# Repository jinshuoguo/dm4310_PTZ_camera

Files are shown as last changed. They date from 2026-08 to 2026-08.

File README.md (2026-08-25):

# DM4310 云台相机

<p align="center">
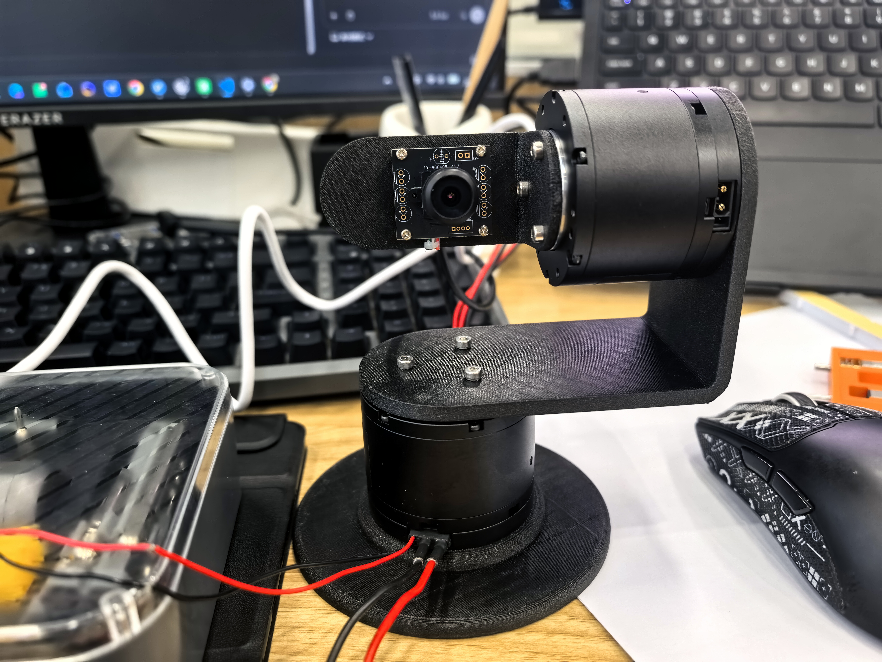
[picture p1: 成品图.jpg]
DM4310 双轴云台相机成品
  
</p>

<p align="center">
  基于双 DM-J4310 电机、USB2FDCAN 与机器视觉构建的双轴智能云台相机
</p>

<p align="center">
  
  
  
  
  
</p>

## 项目简介

这是一个从电机通信、运动控制、机械结构到视觉交互完整落地的双轴云台项目。
系统通过 USB2FDCAN 控制两台 DM-J4310 电机，支持键盘、Xbox 手柄和手机
局域网遥控，并使用相机完成实时画面回传、人脸跟随与手部跟随。

项目不只实现了“让电机转起来”，还围绕真实硬件补充了 S 曲线启停、软限位、
反馈超时保护、超速保护、静摩擦补偿、平滑归零、动作录制复现和断联自动失能，
形成了一套可交互、可演示、可继续扩展的云台控制系统。

## 核心功能

- **双轴实时控制**：经典 CAN 1 Mbps，同一总线独立控制水平轴与俯仰轴。
- **多种交互方式**：键盘、Xbox 左摇杆、手机横屏虚拟摇杆均可控制速度和方向。
- **机器视觉跟随**：基于 MediaPipe 与 OpenCV 实现人脸、手部目标检测和云台闭环跟随。
- **局域网控制台**：手机端同时提供摇杆、实时 MJPEG 画面、状态遥测与功能按钮。
- **位置与动作记忆**：保存/返回双电机位置，录制位置—时间轨迹并自适应复现。
- **拖动示教**：手动拖动一台电机，另一台电机按相对角度同步跟随。
- **高精度归零**：限速、限加速度接近零点，使用捕获区与积分前馈补偿静摩擦。
- **安全保护**：急停、软限位、超速、反馈错误、相机丢失、手柄断开和网络断联保护。

## 动态演示

GIF 会在 GitHub 页面中自动循环播放。每张动图均匀采样了对应演示的完整过程；
点击“高清原片”可以查看或下载 MP4 版本。

<table>
  <tr>
    <td width="50%" align="center">
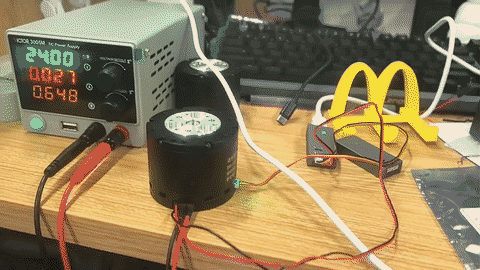
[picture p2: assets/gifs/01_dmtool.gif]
达妙官方工具驱动电机
      <br>
      <b>01 · 官方工具打通硬件链路</b><br>
      <sub>核对电机参数、CAN ID 与通信状态</sub><br>
      <a href="./达妙官方调试软件驱动电机.mp4">高清原片</a>
    </td>
    <td width="50%" align="center">
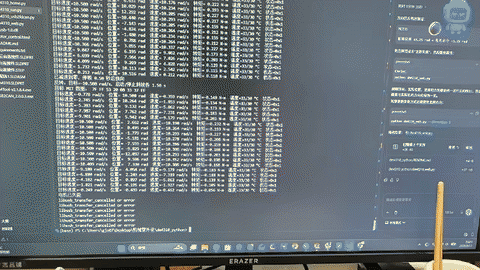
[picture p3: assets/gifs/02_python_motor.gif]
Python 驱动电机
      <br>
      <b>02 · Python 驱动单电机</b><br>
      <sub>USB2FDCAN 使能、控制与反馈解析</sub><br>
      <a href="./python驱动电机.mp4">高清原片</a>
    </td>
  </tr>
  <tr>
    <td width="50%" align="center">
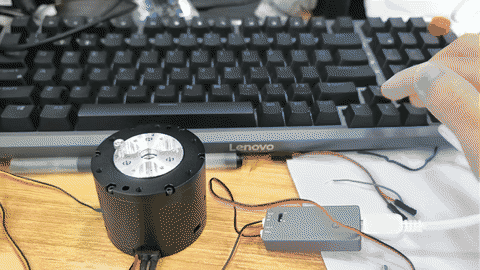
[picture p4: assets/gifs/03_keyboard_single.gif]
键盘控制单电机
      <br>
      <b>03 · 键盘控制单电机</b><br>
      <sub>速度控制与 0.1 秒快速平滑启停</sub><br>
      <a href="./基于python键盘控制电机.mp4">高清原片</a>
    </td>
    <td width="50%" align="center">
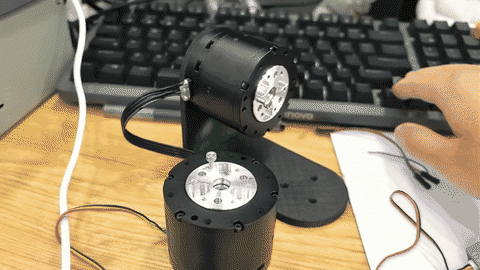
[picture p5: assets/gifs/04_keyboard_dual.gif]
键盘控制双电机
      <br>
      <b>04 · 键盘控制双电机</b><br>
      <sub>两组方向键独立控制水平与俯仰轴</sub><br>
      <a href="./基于python键盘控制双电机.mp4">高清原片</a>
    </td>
  </tr>
  <tr>
    <td width="50%" align="center">
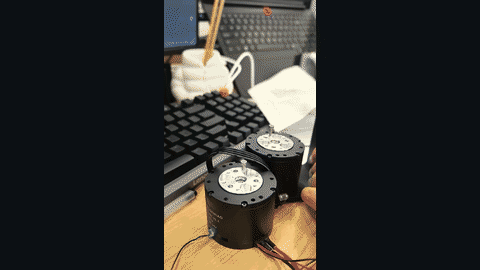
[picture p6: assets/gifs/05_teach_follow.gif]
双电机拖动示教
      <br>
      <b>05 · 双电机拖动示教</b><br>
      <sub>手动拖动一台电机，另一台同步跟随</sub><br>
      <a href="./一个电机控制另一个电机.mp4">高清原片</a>
    </td>
    <td width="50%" align="center">
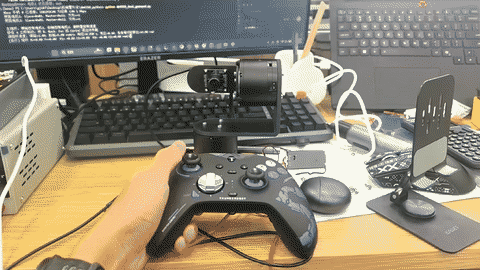
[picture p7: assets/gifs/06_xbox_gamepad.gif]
Xbox 手柄控制云台
      <br>
      <b>06 · Xbox 手柄遥控</b><br>
      <sub>摇杆方向和幅度映射双轴目标速度</sub><br>
      <a href="./xbox手柄控制云台.mp4">高清原片</a>
    </td>
  </tr>
  <tr>
    <td width="50%" align="center">
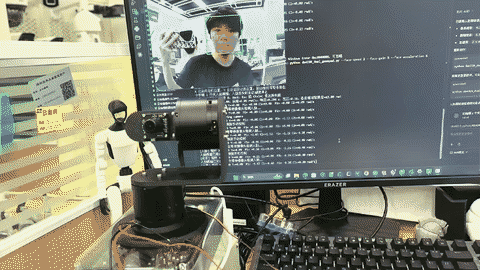
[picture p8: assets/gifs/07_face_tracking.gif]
人脸自动跟随
      <br>
      <b>07 · 人脸自动跟随</b><br>
      <sub>根据人脸中心偏差驱动双轴闭环</sub><br>
      <a href="./人脸跟随.mp4">高清原片</a>
    </td>
    <td width="50%" align="center">
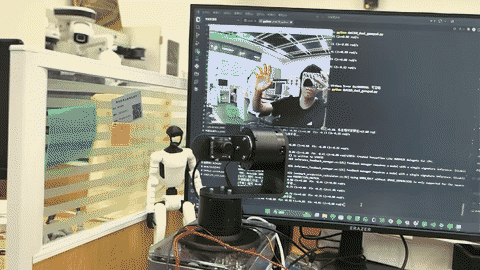
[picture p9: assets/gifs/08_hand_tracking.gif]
手部自动跟随
      <br>
      <b>08 · 手部自动跟随</b><br>
      <sub>使用掌心关键点控制云台视线</sub><br>
      <a href="./手部自动跟踪.mp4">高清原片</a>
    </td>
  </tr>
  <tr>
    <td colspan="2" align="center">
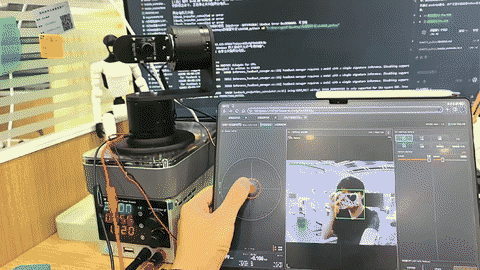
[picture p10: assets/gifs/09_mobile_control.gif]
手机局域网控制云台
      <br>
      <b>09 · 手机局域网控制台</b><br>
      <sub>横屏摇杆、状态遥测、自动功能与实时画面回传</sub><br>
      <a href="./局域网设备控制云台.mp4">高清原片</a>
    </td>
  </tr>
</table>

## 系统架构

```mermaid
flowchart LR
    KB[键盘] --> CTRL
    PAD[Xbox 手柄] --> CTRL
    PHONE[手机横屏控制台] <-->|HTTP / MJPEG| CTRL[Python 控制层]
    CAM[USB 相机] --> VISION[MediaPipe / OpenCV]
    VISION --> CTRL

    CTRL --> PLAN[轨迹规划与模式管理]
    PLAN --> SAFE[软限位 / 超速 / 超时 / 急停]
    SAFE --> SDK[dmcan SDK]
    SDK --> ADAPTER[USB2FDCAN]
    ADAPTER -->|Classic CAN 1 Mbps| M1[电机 1 · Pan\n0x01 / 0x11]
    ADAPTER -->|Classic CAN 1 Mbps| M2[电机 2 · Tilt\n0x02 / 0x12]
```

## 技术实现

### 电机与总线

- 两台 DM-J4310 共用 CAN_H/CAN_L，总线两端配置 120 Ω 终端电阻。
- 电机 1 使用 Slave/Master ID `0x01/0x11`，电机 2 使用 `0x02/0x12`。
- 通过 `dmcan-sdk` 调用 USB2FDCAN，使用经典 CAN 1 Mbps 和 MIT 控制报文。
- 解码位置、速度、转矩、状态与错误码，任一轴异常时联动失能两台电机。

### 运动控制

- 使用限速度、限加速度的速度/位置轨迹，避免阶跃指令冲击机械结构。
- 归零过程根据剩余制动距离调整速度，在零点附近切换到位置捕获阶段。
- 对位置反馈的 ±12.5 rad 回绕进行连续化处理，防止跨量程误判和突然高速旋转。
- 使用渐增位置刚度与限幅积分前馈克服减速器静摩擦，将归零目标误差设为
  `0.005 rad`。
- 动作复现采用自适应时间轴：跟随误差增大时减慢或暂停轨迹，待电机追上后继续。

### 视觉与交互

- 人脸跟随使用 MediaPipe 人脸检测结果，并以关键点中心作为稳定跟踪目标。
- 手部跟随使用 21 个关键点中的掌根和指根区域估计掌心，降低手指动作带来的抖动。
- 视觉控制加入中心死区、目标丢失超时、速度上限和加速度限制。
- 手机端为横屏布局：左侧虚拟摇杆、中间实时画面、右侧自动功能与安全按钮。
- 控制页面使用随机访问令牌；摇杆数据停止 `0.25 s` 后减速，断联超过 `1.2 s`
  自动失能。

## 开发经历

### 1. 打通硬件链路

首先使用达妙官方调试工具确认电机能够校准和转动，并读取固件、电压、CAN ID
与波特率。调试中发现设备虽然在 Windows 中显示为 COM 口，但实际控制接口是
USB2FDCAN SDK，而不是普通串口透传；随后改用 `dmcan-sdk` 完成经典 CAN 报文收发，
解决了“串口有输出但 CAN 帧无法发送”的问题。

### 2. 从单电机测试到安全运动控制

完成使能、MIT 指令打包、反馈解析和异常失能后，先以低速验证单电机正反转。
随后加入 S 曲线缓启动/缓停止、方向映射和相对软限位，使按键控制既敏捷又不会
对结构产生明显冲击。

### 3. 改进高精度归零算法

早期位置插值归零在编码器回绕附近出现过位置跳变和瞬时高速，接近零位时又受到
减速器静摩擦影响，存在稳态误差。为此重新设计两阶段归零：远端采用制动距离限速，
近端先降速再渐增位置刚度，同时加入带限幅、带抗饱和的积分前馈。最终将归零判定
改为“位置与速度同时满足并持续稳定”，目标误差收紧到 `0.005 rad`。

### 4. 扩展双轴、示教与手柄控制

第二台电机接入同一 CAN 总线后，为两轴建立独立 ID、状态与软限位，并实现键盘
并行控制。随后加入拖动示教功能：电机 2 提供低力矩摩擦补偿以便手动拖动，电机 1
跟随其相对角度。Xbox 控制则加入圆形死区、响应曲线、主轴锁定与平滑加减速，减少
上下推动时误触左右轴的问题。

### 5. 加入视觉闭环

在人脸检测方案中，从受光照和侧脸影响较大的传统分类器切换到 MediaPipe；手部跟随
则选取较稳定的掌心区域而不是单个指尖。视觉偏差被转换为两轴目标速度，同时设置
中心死区、目标丢失停车和人工摇杆接管，让自动跟随不会与手动控制争抢控制权。

### 6. 实现动作录制与鲁棒复现

系统以固定周期记录两轴位置和相对时间。直接按原时间播放时，实际电机可能因速度、
负载不同而产生过大跟随误差，因此加入“先返回录制起点 + 自适应时间轴”策略：误差
增大时自动放慢，超过暂停阈值时等待电机追上，仅在触发硬保护阈值时失能。

### 7. 完成局域网手机控制台

最后将手柄端功能迁移到手机横屏网页，整合虚拟摇杆、实时遥测、人脸/手部跟随、
位置记忆、动作录制复现和 MJPEG 画面回传。服务端加入访问令牌、控制心跳和断联
看门狗，使手机可以作为无需安装 App 的便携控制器。

### 8. 机械结构迭代

根据两台电机和相机的实际尺寸设计底盘、云台连接件与相机固定架，并保留 SolidWorks
源文件及 STEP 通用格式，完成从控制算法到实体装配的闭环验证。

## 安全机制

真实电机控制具有风险，项目默认采用以下保护：

- 启动位置附近的相对软限位，防止机构持续绕线或碰撞。
- 超速、错误码、反馈中断、手柄断开和网络断联触发停车或失能。
- 自动跟随、回位和动作复现过程中，人工摇杆输入可立即接管。
- 手机端提供急停按钮，脚本在 `Ctrl+C`、异常或正常退出时发送失能指令。
- 运行任一控制脚本前，应关闭 DMTool 等其他占用 USB2FDCAN 的程序。

> 首次运行请悬空或固定机构、降低速度，并确保随时可以切断 24 V 电源。

## 快速开始

### 1. 环境

- Windows 10/11
- Python 3.13（项目验证环境为 Conda base）
- 达妙 USB2FDCAN 与两台 DM-J4310
- 24 V 直流电源
- USB 相机；Xbox 手柄为可选设备

### 2. 安装依赖

```powershell
Set-Location .\dm4310_python
python -m pip install -r requirements.txt
```

运行前关闭 DMTool 和 USB2CAN 图形工具，避免设备被重复占用。

### 3. 选择控制方式

```powershell
# 单电机低速验证
python dm4310_usb2fdcan.py

# 双轴键盘控制
python dm4310_dual_keyboard.py

# Xbox 手柄、视觉跟随、位置记忆和动作录制
python dm4310_dual_gamepad.py

# 手机局域网控制与视频回传
python dm4310_mobile.py
```

更完整的接线、参数和各脚本使用方法见
[Python 控制说明](./dm4310_python/README.md)。

## 项目结构

```text
云台相机/
├─ README.md                         # GitHub 项目主页
├─ 成品图.jpg                        # 实物展示
├─ *.mp4                            # 功能演示视频
├─ assets/gifs/                     # README 轻量循环动图
├─ tools/make_readme_gifs.py        # MP4 批量生成 GIF 预览工具
├─ *.SLDPRT / *.SLDASM / *.STEP     # 机械设计源文件与通用模型
└─ dm4310_python/
   ├─ dm4310_usb2fdcan.py           # 单电机通信与低速测试
   ├─ dm4310_home.py                # 高精度平滑归零
   ├─ dm4310_keyboard.py            # 单电机键盘控制
   ├─ dm4310_dual_keyboard.py       # 双电机键盘控制
   ├─ dm4310_teach_follow.py        # 拖动示教跟随
   ├─ dm4310_dual_gamepad.py        # 手柄、视觉、录制复现主程序
   ├─ dm4310_face_tracker.py        # 人脸与手部检测封装
   ├─ dm4310_mobile.py              # 局域网手机控制服务
   ├─ mobile_controller.html        # 手机横屏控制界面
   ├─ dm4310_web.py                 # 单轴网页位置控制服务
   └─ requirements.txt              # Python 依赖
```

## 后续计划

- 接入小智 AI 语音，通过 MCP 将自然语言安全映射为跟随、回位、录制和急停等离散工具。
- 增加双轴机械零位开关与上电自动标定。
- 将相机跟踪升级为带目标选择和丢失重识别的多目标跟踪。
- 保存动作轨迹到文件，并提供轨迹编辑、命名和管理界面。

## 说明

本仓库面向个人学习、机器人控制实验和作品集展示。项目直接驱动真实电机，复现时请
根据自己的机械结构重新确认 CAN ID、安装方向、软限位、电源能力和急停方案。

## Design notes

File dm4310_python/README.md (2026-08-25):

# DM4310 云台相机

基于双轴 DM-J4310 电机、USB2FDCAN、相机视觉、手柄与局域网手机端的云台相机控制项目。

当前设备在调试工具中显示为 `COM10-USB2FDCAN`，应使用 USB2FDCAN SDK，
而不是旧版 COM 串口封装。

## 安装

依赖和官方 Windows DLL 已放入当前目录。请使用 Conda base 的 Python 3.13，
不要使用指向 Python 3.15 alpha 的 `py` 启动器。

运行前必须完全关闭 DM_Tools 和 USB2CAN 图形工具，确保 COM10 没有被占用。

## USB2FDCAN 首次低速测试

1. 完全关闭 DMTool 和 USB2CAN 图形程序。
2. 固定或悬空电机。
3. 在 `(base)` 终端运行：

```powershell
python dm4310_usb2fdcan.py
```

默认参数：

- Slave ID：0x01
- Master ID：0x11
- CAN：经典 CAN 1 Mbps
- 速度：0.5 rad/s
- 时间：5 秒
- 缓启动、缓停止时间：各 1.5 秒（S 曲线）
- MIT 参数：KP=0、KD=1、Torque=0

程序结束、报错或按 `Ctrl+C` 时都会发送失能命令。

根据当前调试工具截图，实际 Slave ID 是 `0x01`，Master ID 是 `0x11`；
新脚本也以这两个值为默认值。

修改速度和运行时间：

```powershell
python dm4310_usb2fdcan.py --speed -0.5 --duration 3
```

用 `--ramp-time` 调整启动和停止的平滑时间，例如各用 2 秒：

```powershell
python dm4310_usb2fdcan.py --speed 0.5 --duration 8 --ramp-time 2
```

自动正反转（每个方向运行 5 秒，换向前零速停顿 0.5 秒）：

```powershell
python dm4310_usb2fdcan.py --speed 0.5 --duration 5 --ramp-time 1.5 --bidirectional
```

可用 `--pause-time 1` 将换向停顿改为 1 秒。`--duration` 表示每个方向
各自的运行时间，因此上述正反转流程总时长约为 10.5 秒。

## 缓慢移动到零位

确认从当前位置到 `0 rad` 的运动路径没有机械干涉，然后运行：

```powershell
python dm4310_home.py --duration 20 --max-speed 0.3 --max-acceleration 0.3 --min-speed 0.12 --kp 2 --kd 1 --capture-ki 1 --integral-torque-limit 0.35 --tolerance 0.005
```

程序采用两阶段归零：远离零点时根据剩余制动距离计算目标速度，同时通过
`--min-speed` 克服静摩擦；进入默认 `0.2 rad` 捕获区后，速度先降到零，
位置 KP 再用 1 秒从零平滑增加到设定值。进入零点容差并低速停稳后才算
归零成功。默认实测速度超过 `2 rad/s` 会立即停止并失能，位置误差连续
3 秒没有改善也会停止。

捕获阶段还会使用带限幅的积分前馈力矩消除减速器静摩擦或恒定负载造成的
稳态误差。默认补偿最多 `0.35 N·m`，运行输出中的 `Tff` 是当前补偿值。
默认归零误差要求为 `0.005 rad`，需要连续稳定 0.5 秒，并在零位继续保持
2 秒后才检查最终误差。

它不会改写编码器零点；失能后也不会继续提供保持力矩。`--duration` 是允许
的最大归零时间，超时会直接失能。MIT 位置反馈在 ±12.5 rad 处会回绕，脚本
不会再把首次反馈直接作为绝对位置指令，以免跨量程时突然高速回转。

## 网页实时角度控制

完全关闭 DMTool，然后在 `(base)` 终端运行：

```powershell
python dm4310_web.py
```

当前机构的前端方向映射默认为反向（`--direction -1`），使画面正方向与实际
机构正方向一致。如果更换安装方向后需要恢复电机原始坐标，可运行
`python dm4310_web.py --direction 1`。

程序会打开 `http://127.0.0.1:8765/`。操作顺序：

1. 点击“连接设备”，此时电机仍保持失能。
2. 点击“安全归零”，等待状态变成 `TRACKING`。
3. 拖动中央角度盘，或使用 ±45°/±90°/回零快捷按钮。
4. 结束时点击红色“立即失能”，再关闭终端。

浏览器只发送目标角，本地 Python 控制线程以 100 Hz 生成限速、限加速度的
MIT 位置轨迹。目标范围限制为 ±3 rad，实测速度超过 2 rad/s、跟随误差超过
0.8 rad、反馈中断或前端心跳丢失 1 秒都会自动失能。服务默认只监听本机，
不要使用 `--host 0.0.0.0` 暴露到局域网。

## 键盘左右转动控制

关闭网页服务、DMTool 和 USB2CAN 工具，在前台终端运行：

```powershell
python dm4310_keyboard.py
```

- 按住 `←`：向左转动。
- 按住 `→`：向右转动。
- 每按一次 `↑`：速度增加 `0.5 rad/s`，最高 `5 rad/s`。
- 每按一次 `↓`：速度减少 `0.5 rad/s`，最低 `0.5 rad/s`。
- 松开方向键：平滑减速到零。
- 按住空格：制动。
- 按 `Esc` 或 `Ctrl+C`：停止并失能。

默认速度 `2.5 rad/s`，按下和松开方向键的速度指令分别在 `0.1 s` 内完成
加速与减速（等效 `25 rad/s²`），并以脚本启动位置为中心设置 ±3 rad 软限位。
可用 `--speed 1 --ramp-time 0.2 --position-limit 1.5` 降低响应和范围。
当前机构方向默认 `--direction -1`，若方向不符可改为 `--direction 1`。

## 两台电机同步键盘控制

第二台电机使用 CAN ID `0x02`、Master ID `0x12` 时运行：

```powershell
python dm4310_dual_keyboard.py
```

左右键只控制电机1，上下键只控制电机2；两台可以同时按键、独立运动。
空格同时制动，任意一台反馈中断、状态异常或超速时，脚本都会停止并失能
两台。若第二台机械安装方向相反，可运行：

```powershell
python dm4310_dual_keyboard.py --direction-1 -1 --direction-2 1
```

两台电机共享 CAN_H/CAN_L 总线并使用不同 ID；24V 电源应并联供电。总线
只在物理两端设置 120Ω 终端电阻，不要在每个中间节点重复增加终端电阻。

## Xbox 左摇杆控制两台电机

连接 Xbox 手柄并关闭 DMTool、网页服务等占用 USB2FDCAN 的程序，然后运行：

```powershell
python dm4310_dual_gamepad.py
```

左摇杆横轴控制电机1、纵轴控制电机2，偏转方向决定旋转方向，偏转幅度线性
决定速度。纵轴满行程默认对应 `5 rad/s`，横轴为其 60%，即 `3 rad/s`；
摇杆回中后在约 `0.25 s` 内停止，默认圆形死区为 10%。主轴锁定会在明显
上下推动时忽略少量左右偏移，减少误触；接近斜向推动时仍可同时控制两台。
按住 `A` 立即制动；按 `B`、`Back`、键盘 `Esc` 或 `Ctrl+C` 会停止并
失能两台电机。手柄运行中断开也会触发失能。

按一下 `X` 会记录两台电机相对脚本启动位置的当前位置；之后按一下 `Y`，
两台电机会以默认最高 `1.5 rad/s` 自动返回记录位置。回位达到 ±0.02 rad
并稳定后结束。回位过程中拨动左摇杆或按 `A` 会立刻取消回位并允许人工
接管。可使用 `--return-speed 0.8` 降低回位速度，或使用
`--return-tolerance 0.01` 提高回位精度。

按一下手柄十字键 `↓` 开启人脸跟随，再按一次关闭。首次开启时会按名称打开
`icspring camera` 外置相机和预览窗口，不会再误用笔记本的
`Integrated Camera`。人脸检测使用 MediaPipe BlazeFace Short Range，
并以双眼和鼻尖三个关键点的中心作为云台目标，取代了原先容易受光照、侧脸
影响的 Haar 分类器；画面中绿色框标出当前跟随的人脸和置信度。默认最大
跟随速度 `1.5 rad/s`、加速度 `4 rad/s²`，人脸靠近画面中心 8% 的区域内
不移动。人脸丢失超过 0.5 秒会减速停止，不会自行搜索。跟随期间拨动左摇杆
或按 `A` 会立即退出跟随并交回手动控制。当前机构的人脸水平跟随方向默认
为 `--face-direction-x -1`，摇杆的左右方向不受这个参数影响。

按一下手柄十字键 `↑` 开启手部跟随，再按一次关闭。手部跟随与人脸跟随
共用 `icspring camera`，两种模式不能同时运行。程序使用 MediaPipe 的 21
个手部关键点，并用掌根和四个指根的平均中心控制云台，因此手指张合不会
明显改变跟随目标。默认最大速度 `1.5 rad/s`、加速度 `4 rad/s²`、画面
中心死区 10%；手部丢失超过 0.5 秒会减速停止。拨动摇杆或按 `A` 会立即
退出手部跟随。

调整手部跟随速度、方向或灵敏度：

```powershell
python dm4310_dual_gamepad.py --hand-speed 1 --hand-gain 2 --hand-direction-x 1 --hand-direction-y -1
```

如果更换了其他型号的摄像头、跟随方向相反或不需要预览窗口，可运行：

```powershell
python dm4310_dual_gamepad.py --camera-name "新相机名称" --face-direction-x -1 --face-direction-y -1 --no-camera-preview
```

人脸与手部检测依赖 `mediapipe`、`opencv-contrib-python`，安装全部依赖可运行：

```powershell
python -m pip install -r requirements.txt
```

按一下手柄十字键 `←` 开始录制两台电机的位置—时间轨迹，再按一次 `←`
结束录制。随后按十字键 `→`，设备会先以安全速度返回录制起点，再按记录的
时间顺序复现刚才的双电机动作。默认每 0.02 秒采样一次，最长录制 30 秒；
复现速度限制为 `3 rad/s`、加速度为 `6 rad/s²`。复现期间拨动左摇杆或按
`A` 会立即取消并交回人工控制。轨迹使用自适应时间轴：误差超过 0.3 rad
开始自动减慢，达到 0.6 rad 时暂停轨迹时间并等待电机追上；只有误差超过
1.2 rad 的硬保护阈值才会停止并失能。因此录制动作快于复现速度限制时，
动作会自动放慢而不会直接报错。自动
返回录制起点时，两台电机都进入 ±0.05 rad 范围并停稳后开始复现；这个
容差可通过 `--replay-start-tolerance` 调整。

调整最长录制时间或降低复现速度：

```powershell
python dm4310_dual_gamepad.py --record-max-duration 60 --replay-speed 1.5 --replay-acceleration 3
```

降低最高速度、增大死区或改变摇杆响应曲线：

```powershell
python dm4310_dual_gamepad.py --max-speed 3 --x-speed-scale 0.5 --deadzone 0.15 --response-exponent 1.5
```

`response-exponent=1` 为线性；大于 1 时中心区域更细腻。可通过
`--axis-lock-ratio 0` 关闭主轴锁定。两台电机仍分别受到启动位置 ±3 rad
软限位、反馈超时和超速保护。当前手柄控制的两轴方向默认均为 `1`；如果
以后更改电机安装方向，可分别使用 `--direction-1 -1` 或
`--direction-2 -1` 反转对应电机。

## 局域网手机遥控两台电机

先让手机和电脑连接同一个 Wi-Fi，完全关闭 DMTool 和其他
会占用 USB2FDCAN 的脚本，然后在电脑上运行：

```powershell
python dm4310_mobile.py
```

终端会输出一个带随机控制码的局域网地址，例如：

```text
http://192.168.1.23:8766/?token=xxxxxxxx
```

用手机浏览器打开这个完整地址。如果 Windows 弹出防火墙询问，
只允许“专用网络”即可。页面中先点“连接设备”，将摇杆回中后
长按“使能” 1 秒；摇杆左右控制电机1，上下控制电机2，幅度
决定速度。页面上可实时调整最高速度和加减速时间。
手机端专为横屏操作设计：左侧是摇杆和两电机遥测，中间是实时画面，
右侧是跟随、记录/复现、运动参数和安全按钮。竖屏时页面会提示旋转手机。

手机页面也包含与 Xbox 手柄相同的扩展功能：

- `CAM` 开启 `icspring camera` 局域网画面回传；默认约 15 FPS。
- `人脸跟随` / `手部跟随` 分别对应手柄十字键 `↓` / `↑`，点击后
  会自动打开回传画面并显示检测框、关键点与画面偏差。
- `记录位置` / `返回位置` 对应手柄 `X` / `Y`。
- `动作录制` 点一次开始、再点一次停止；`动作复现` 会先自动
  返回录制起点，再按记录时间轴复现，对应手柄十字键 `←` / `→`。
- `取消自动` 会停止跟随、回位或复现；在任何自动模式中拨动
  手机摇杆也会立即切回手动控制。

视频只在手机打开回传窗口时传输；关闭窗口后会断开手机端视频流以
节省带宽，但正在进行的人脸/手部检测不会中断。需要降低网络负载时：

```powershell
python dm4310_mobile.py --stream-fps 10 --jpeg-quality 60
```

默认仍使用已验证的两组 ID：电机1 `0x01/0x11`，电机2
`0x02/0x12`，经典 CAN 1 Mbps。最高速度默认 `3 rad/s`，水平轴是
该值的 60%，两轴都受启动位置 ±3 rad 软限位保护。手机停止发送
摇杆数据 0.25 秒后会先减速到零；断联超过 1.2 秒会自动失能
两台电机。手机页面上的“急停 / 失能”也可随时同时失能两台。

需要改端口、方向或初始速度时：

```powershell
python dm4310_mobile.py --port 9000 --max-speed 2 --direction-1 -1 --direction-2 1
```

如果手机打不开地址，依次检查：电脑网络类型是“专用网络”、
手机没有使用蜂窝网络/VPN，以及路由器没有开启客户端隔离。不要将这个
服务映射到公网。

## 拖动电机2示教电机1

让电机2以低力矩助力模式手动拖动，电机1跟随其相对角度：

```powershell
python dm4310_teach_follow.py
```

脚本启动时两台电机的位置分别作为相对零点，不会改写编码器零位。电机2
默认先安全失能，再以零位置/速度刚度使能，仅输出最高 `0.10 N·m` 的低速
顺向摩擦补偿；补偿随速度增加而衰减，在 0.6 rad/s 时归零，降低松手自转
风险。电机1使用限速速度闭环跟随。默认比例 1:1、最高速度 2.5 rad/s、
相对软限位 ±3 rad。

如果需要反向跟随或降低速度：

```powershell
python dm4310_teach_follow.py --ratio -1 --max-speed 1.5
```

调整助力或恢复完全失能拖动：

```powershell
python dm4310_teach_follow.py --assist-torque 0.15
python dm4310_teach_follow.py --assist-torque 0
```

运行期间按 `Esc` 或 `Ctrl+C` 会失能两台；任一反馈异常、电机超速或电机2
状态与所选助力模式不符也会立即停止。

`dm4310_run.py` 是旧版串口 USB2CAN 的兼容脚本，不适用于当前 USB2FDCAN。

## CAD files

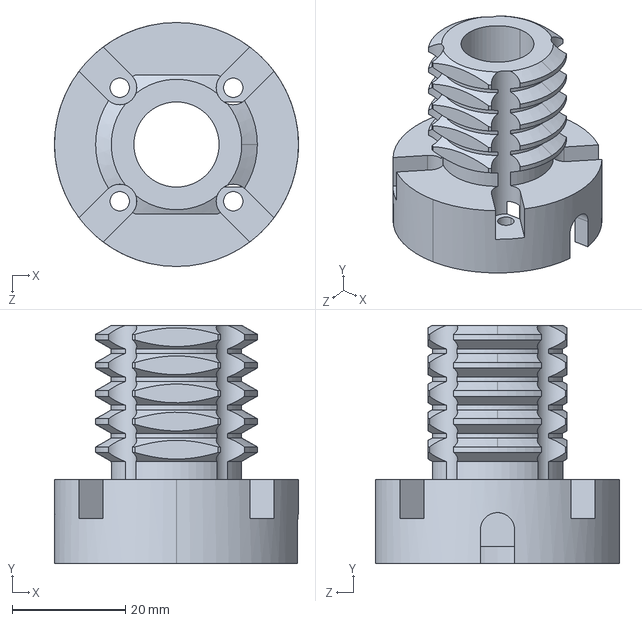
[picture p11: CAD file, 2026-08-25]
手部连接件.STEP
43.0 x 42.0 x 43.0 mm

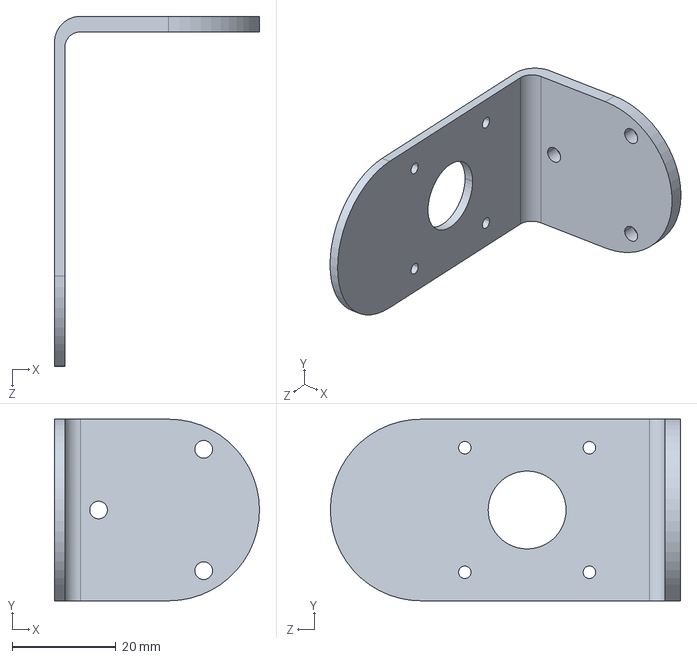
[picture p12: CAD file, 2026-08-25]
云台相机固定架.STEP
39.5 x 35.0 x 67.5 mm

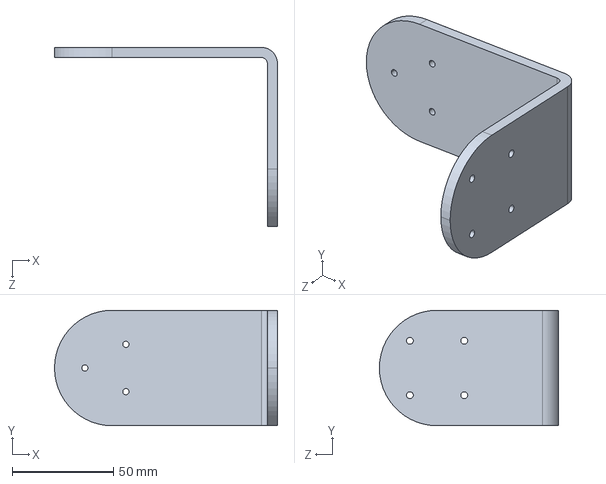
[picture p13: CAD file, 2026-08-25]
云台连接件.STEP
110.1 x 57.0 x 88.5 mm

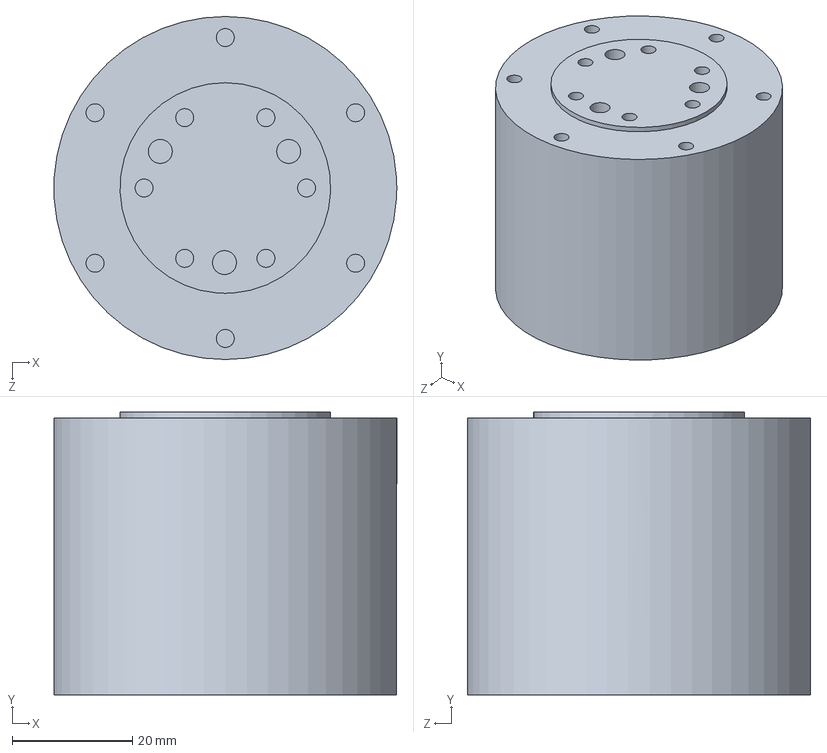
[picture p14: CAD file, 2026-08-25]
dm4310.SLDPRT
56.9 x 47.0 x 57.0 mm

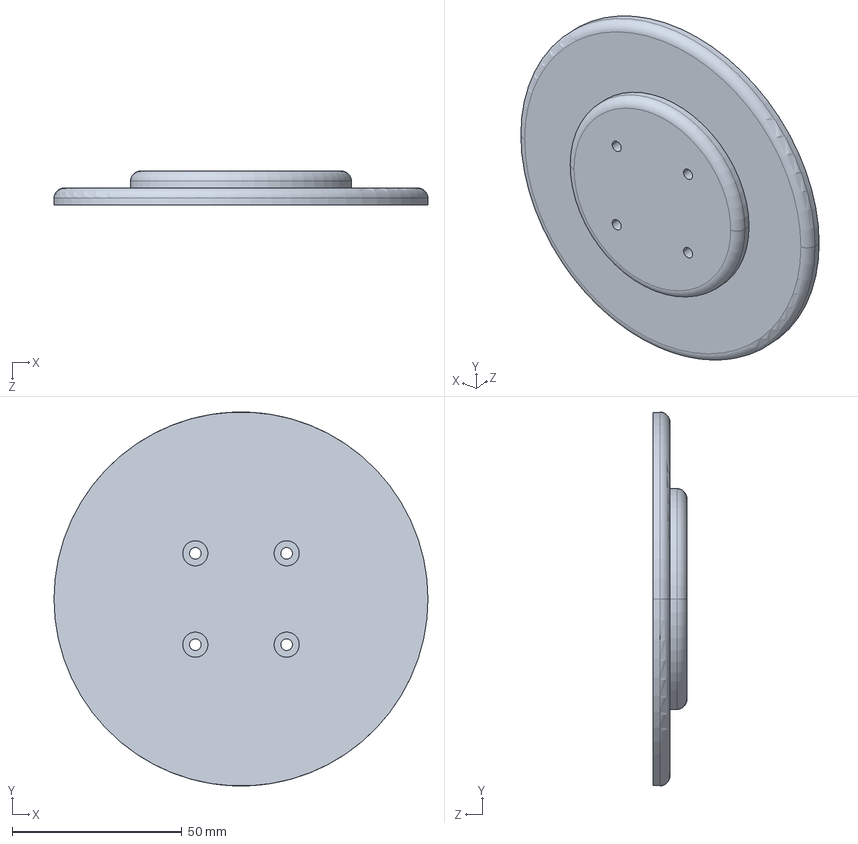
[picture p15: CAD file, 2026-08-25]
云台底盘.STEP
110.0 x 110.0 x 10.0 mm

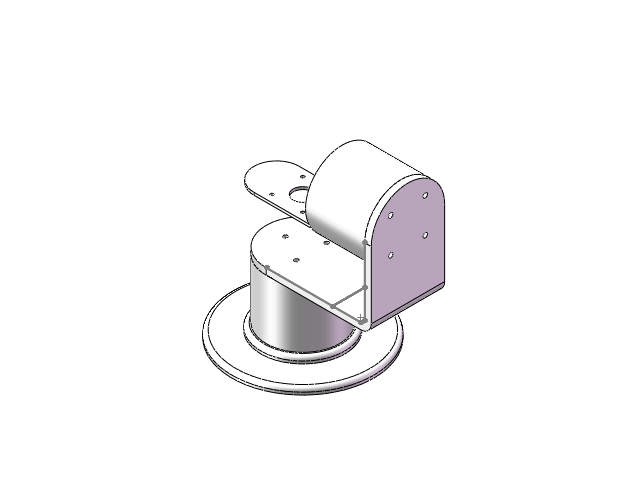
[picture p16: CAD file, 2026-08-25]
装配体1.SLDASM
dm4310 x 2
云台连接件
云台底盘
云台相机固定架

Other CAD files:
云台底盘.SLDPRT
云台相机固定架.SLDPRT
云台连接件.SLDPRT
手部连接件.SLDPRT

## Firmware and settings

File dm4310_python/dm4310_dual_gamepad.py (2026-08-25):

"""使用 Xbox 左摇杆独立控制两台 DM-J4310。

左摇杆横轴控制电机1，纵轴控制电机2；偏转量线性映射为速度。
默认纵轴满摇杆速度为 5 rad/s，横轴为其 60%；速度指令在 0.25 秒内
完成加减速。主轴锁定会抑制上下推动时产生的少量左右串扰。
"""

from __future__ import annotations

import argparse
import ctypes
import math
import time
from ctypes import wintypes
from dataclasses import dataclass

from dmcan import DmCanContext, dmcan_device_type

from dm4310_dual_keyboard import MotorRuntime, checked_state
from dm4310_face_tracker import FaceTracker
from dm4310_keyboard import VK_ESCAPE, clamp, key_is_down, unwrap_delta
from dm4310_usb2fdcan import (
    CONTROL_PERIOD_S,
    Feedback,
    configure_classic_can_1m,
    pack_mit,
    parse_int,
    send,
    special,
    wait_until_enabled,
)


ERROR_DEVICE_NOT_CONNECTED = 1167
XINPUT_GAMEPAD_BACK = 0x0020
XINPUT_GAMEPAD_DPAD_UP = 0x0001
XINPUT_GAMEPAD_DPAD_DOWN = 0x0002
XINPUT_GAMEPAD_DPAD_LEFT = 0x0004
XINPUT_GAMEPAD_DPAD_RIGHT = 0x0008
XINPUT_GAMEPAD_A = 0x1000
XINPUT_GAMEPAD_B = 0x2000
XINPUT_GAMEPAD_X = 0x4000
XINPUT_GAMEPAD_Y = 0x8000


@dataclass(frozen=True)
class MotionSample:
    elapsed: float
    position_1: float
    position_2: float


class XInputGamepad(ctypes.Structure):
    _fields_ = [
        ("wButtons", wintypes.WORD),
        ("bLeftTrigger", wintypes.BYTE),
        ("bRightTrigger", wintypes.BYTE),
        ("sThumbLX", ctypes.c_short),
        ("sThumbLY", ctypes.c_short),
        ("sThumbRX", ctypes.c_short),
        ("sThumbRY", ctypes.c_short),
    ]


class XInputState(ctypes.Structure):
    _fields_ = [
        ("dwPacketNumber", wintypes.DWORD),
        ("Gamepad", XInputGamepad),
    ]


class XboxController:
    """最小化 XInput 封装，不依赖 pygame。"""

    def __init__(self, index: int, deadzone: float, exponent: float):
        self.index = index
        self.deadzone = deadzone
        self.exponent = exponent
        self._get_state = self._load_xinput()

    @staticmethod
    def _load_xinput():
        errors: list[str] = []
        for dll_name in (
            "xinput1_4.dll",
            "xinput1_3.dll",
            "xinput9_1_0.dll",
        ):
            try:
                dll = ctypes.WinDLL(dll_name)
                function = dll.XInputGetState
                function.argtypes = [
                    wintypes.DWORD,
                    ctypes.POINTER(XInputState),
                ]
                function.restype = wintypes.DWORD
                return function
            except (OSError, AttributeError) as exc:
                errors.append(f"{dll_name}: {exc}")
        raise RuntimeError("无法加载 Windows XInput：" + "；".join(errors))

    @staticmethod
    def _normalize_axis(value: int) -> float:
        divisor = 32767.0 if value >= 0 else 32768.0
        return value / divisor

    def read(self) -> tuple[float, float, int]:
        state = XInputState()
        result = self._get_state(self.index, ctypes.byref(state))
        if result == ERROR_DEVICE_NOT_CONNECTED:
            raise RuntimeError(f"Xbox 手柄 {self.index} 已断开")
        if result != 0:
            raise RuntimeError(f"读取 Xbox 手柄失败，XInput 错误码 {result}")

        x = self._normalize_axis(state.Gamepad.sThumbLX)
        y = self._normalize_axis(state.Gamepad.sThumbLY)
        magnitude = min(1.0, math.hypot(x, y))
        if magnitude <= self.deadzone:
            return 0.0, 0.0, state.Gamepad.wButtons

        # 圆形死区：越过死区后重新映射至完整的 0..1 行程。
        mapped_magnitude = (magnitude - self.deadzone) / (1.0 - self.deadzone)
        mapped_magnitude = mapped_magnitude ** self.exponent
        scale = mapped_magnitude / magnitude
        return x * scale, y * scale, state.Gamepad.wButtons


def suppress_cross_axis(
    x: float,
    y: float,
    lock_ratio: float,
) -> tuple[float, float]:
    """一个轴明显占优时，将另一个轴的摇杆串扰清零。"""
    if lock_ratio == 0:
        return x, y
    if abs(y) > abs(x) * lock_ratio:
        return 0.0, y
    if abs(x) > abs(y) * lock_ratio:
        return x, 0.0
    return x, y


def face_error_to_velocity(
    error: float,
    deadzone: float,
    gain: float,
    speed_limit: float,
) -> float:
    """将归一化画面偏差转换成带死区、限幅的速度。"""
    if abs(error) <= deadzone:
        return 0.0
    effective_error = math.copysign(
        (abs(error) - deadzone) / (1.0 - deadzone),
        error,
    )
    return clamp(gain * effective_error, speed_limit)


def interpolate_motion(
    samples: list[MotionSample],
    elapsed: float,
    start_index: int,
) -> tuple[tuple[float, float], tuple[float, float], int, bool]:
    """线性插值录制位置，并计算相邻采样点的前馈速度。"""
    if elapsed >= samples[-1].elapsed:
        final = samples[-1]
        return (
            (final.position_1, final.position_2),
            (0.0, 0.0),
            max(0, len(samples) - 2),
            True,
        )

    index = min(start_index, len(samples) - 2)
    while index + 1 < len(samples) and samples[index + 1].elapsed < elapsed:
        index += 1
    first = samples[index]
    second = samples[index + 1]
    duration = max(1e-6, second.elapsed - first.elapsed)
    alpha = max(0.0, min(1.0, (elapsed - first.elapsed) / duration))
    positions = (
        first.position_1 + alpha * (second.position_1 - first.position_1),
        first.position_2 + alpha * (second.position_2 - first.position_2),
    )
    velocities = (
        (second.position_1 - first.position_1) / duration,
        (second.position_2 - first.position_2) / duration,
    )
    return positions, velocities, index, False


def validate_args(args: argparse.Namespace) -> tuple[float, float]:
    if args.direction_1 not in (-1, 1) or args.direction_2 not in (-1, 1):
        raise ValueError("direction-1 和 direction-2 只能是 -1 或 1")
    if args.slave_id_1 == args.slave_id_2:
        raise ValueError("两台电机的 CAN ID 不能相同")
    if args.master_id_1 == args.master_id_2:
        raise ValueError("两台电机的 Master ID 不能相同")
    if not 0 < args.max_speed <= 5.0:
        raise ValueError("max-speed 必须在 0..5 rad/s 之间")
    if not 0.1 <= args.x_speed_scale <= 1.0:
        raise ValueError("x-speed-scale 必须在 0.1..1 之间")
    if not 0.02 <= args.ramp_time <= 2.0:
        raise ValueError("ramp-time 必须在 0.02..2 秒之间")
    if not 0.0 <= args.deadzone <= 0.5:
        raise ValueError("deadzone 必须在 0..0.5 之间")
    if not 0.5 <= args.response_exponent <= 3.0:
        raise ValueError("response-exponent 必须在 0.5..3 之间")
    if args.axis_lock_ratio != 0 and not 1.05 <= args.axis_lock_ratio <= 5.0:
        raise ValueError("axis-lock-ratio 必须为 0，或在 1.05..5 之间")
    if not 0 <= args.kd <= 5.0:
        raise ValueError("kd 必须在 0..5 之间")
    if not 0 < args.position_limit < 12.5:
        raise ValueError("position-limit 必须在 0..12.5 rad 之间")
    if args.overspeed_limit <= args.max_speed:
        raise ValueError("overspeed-limit 必须大于 max-speed")
    if not 0 < args.return_speed <= args.max_speed:
        raise ValueError("return-speed 必须在 0..max-speed 之间")
    if not 0 < args.return_gain <= 20.0:
        raise ValueError("return-gain 必须在 0..20 之间")
    if not 0 <= args.return_min_speed <= args.return_speed:
        raise ValueError("return-min-speed 必须在 0..return-speed 之间")
    if not 0.005 <= args.return_tolerance <= 0.2:
        raise ValueError("return-tolerance 必须在 0.005..0.2 rad 之间")
    if not 0 <= args.camera_index <= 10:
        raise ValueError("camera-index 必须在 0..10 之间")
    if not 0 < args.face_speed <= 2.0:
        raise ValueError("face-speed 必须在 0..2 rad/s 之间")
    if not 0 < args.face_gain <= 10.0:
        raise ValueError("face-gain 必须在 0..10 之间")
    if not 0 <= args.face_deadzone <= 0.4:
        raise ValueError("face-deadzone 必须在 0..0.4 之间")
    if not 0.2 <= args.face_timeout <= 2.0:
        raise ValueError("face-timeout 必须在 0.2..2 秒之间")
    if not 0.1 <= args.face_acceleration <= 10.0:
        raise ValueError("face-acceleration 必须在 0.1..10 rad/s² 之间")
    if args.face_direction_x not in (-1, 1) or args.face_direction_y not in (-1, 1):
        raise ValueError("face-direction-x/y 只能是 -1 或 1")
    if not 0 < args.hand_speed <= 2.0:
        raise ValueError("hand-speed 必须在 0..2 rad/s 之间")
    if not 0 < args.hand_gain <= 10.0:
        raise ValueError("hand-gain 必须在 0..10 之间")
    if not 0 <= args.hand_deadzone <= 0.4:
        raise ValueError("hand-deadzone 必须在 0..0.4 之间")
    if not 0.2 <= args.hand_timeout <= 2.0:
        raise ValueError("hand-timeout 必须在 0.2..2 秒之间")
    if not 0.1 <= args.hand_acceleration <= 10.0:
        raise ValueError("hand-acceleration 必须在 0.1..10 rad/s² 之间")
    if args.hand_direction_x not in (-1, 1) or args.hand_direction_y not in (-1, 1):
        raise ValueError("hand-direction-x/y 只能是 -1 或 1")
    if not 1.0 <= args.record_max_duration <= 120.0:
        raise ValueError("record-max-duration 必须在 1..120 秒之间")
    if not 0.01 <= args.record_interval <= 0.1:
        raise ValueError("record-interval 必须在 0.01..0.1 秒之间")
    if not 0 < args.replay_speed <= 5.0:
        raise ValueError("replay-speed 必须在 0..5 rad/s 之间")
    if not 0 < args.replay_gain <= 20.0:
        raise ValueError("replay-gain 必须在 0..20 之间")
    if not 0.1 <= args.replay_acceleration <= 20.0:
        raise ValueError("replay-acceleration 必须在 0.1..20 rad/s² 之间")
    if not 0.1 <= args.replay_error_limit <= 2.0:
        raise ValueError("replay-error-limit 必须在 0.1..2 rad 之间")
    if not args.replay_error_limit < args.replay_hard_error_limit <= 2.5:
        raise ValueError(
            "replay-hard-error-limit 必须大于 replay-error-limit，且不超过 2.5 rad"
        )
    if not 0.01 <= args.replay_start_tolerance <= 0.2:
        raise ValueError("replay-start-tolerance 必须在 0.01..0.2 rad 之间")
    if not 0 <= args.controller_index <= 3:
        raise ValueError("controller-index 必须在 0..3 之间")

    acceleration_y = (
        args.acceleration
        if args.acceleration is not None
        else args.max_speed / args.ramp_time
    )
    acceleration_x = (
        args.acceleration
        if args.acceleration is not None
        else args.max_speed * args.x_speed_scale / args.ramp_time
    )
    if not 0 < acceleration_x <= 100.0 or not 0 < acceleration_y <= 100.0:
        raise ValueError("acceleration 必须在 0..100 rad/s² 之间")
    return acceleration_x, acceleration_y


def run(args: argparse.Namespace) -> None:
    accelerations = validate_args(args)
    controller = XboxController(
        args.controller_index,
        args.deadzone,
        args.response_exponent,
    )

    # 在打开电机之前确认手柄确实存在且摇杆已回中。
    stick_x, stick_y, initial_buttons = controller.read()
    if math.hypot(stick_x, stick_y) > 0.05:
        raise RuntimeError("启动前请松开左摇杆并让它回到中心")

    face_tracker = FaceTracker(
        camera_index=args.camera_index,
        camera_name=args.camera_name,
        preview=not args.no_camera_preview,
    )

    context = None
    device = None
    channel_enabled = False
    enabled_motors: list[MotorRuntime] = []

    try:
        context = DmCanContext()
        count = context.find_devices(dmcan_device_type.USB2CANFD)
        if count <= 0:
            raise RuntimeError(
                "没有找到 USB2FDCAN；请关闭网页服务、DMTool/USB2CAN 后重新插拔"
            )
        if args.device_index >= count:
            raise RuntimeError(f"只发现 {count} 个设备，device-index 超出范围")

        device = context.get_device(args.device_index)
        if not device.open():
            raise RuntimeError("USB2FDCAN 打开失败，设备可能被其他程序占用")

        feedback_1 = Feedback(
            args.slave_id_1,
            args.master_id_1,
            args.channel,
        )
        feedback_2 = Feedback(
            args.slave_id_2,
            args.master_id_2,
            args.channel,
        )
        motors = [
            MotorRuntime(
                "电机1",
                args.slave_id_1,
                args.master_id_1,
                args.direction_1,
                feedback_1,
            ),
            MotorRuntime(
                "电机2",
                args.slave_id_2,
                args.master_id_2,
                args.direction_2,
                feedback_2,
            ),
        ]

        def dispatch_feedback(callback_device, frame) -> None:
            feedback_1.callback(callback_device, frame)
            feedback_2.callback(callback_device, frame)

        device.hook_recv_callback(dispatch_feedback)
        configure_classic_can_1m(device, args.channel)
        channel_enabled = True

        for motor in motors:
            special(device, args.channel, motor.slave_id, 0xFD)
        time.sleep(0.2)

        zero_speed = pack_mit(0.0, 0.0, 0.0, args.kd, 0.0)
        for _ in range(3):
            for motor in motors:
                send(device, args.channel, motor.slave_id, zero_speed)
            time.sleep(CONTROL_PERIOD_S)

        print(
            f"Xbox 手柄 {args.controller_index} 已连接；"
            "USB2FDCAN 为经典 CAN 1 Mbps"
        )
        for motor in motors:
            print(
                f"使能{motor.name}：Slave=0x{motor.slave_id:02X}，"
                f"Master=0x{motor.master_id:02X}，方向={motor.direction:+d}"
            )
            state = wait_until_enabled(
                device,
                motor.feedback,
                args.channel,
                motor.slave_id,
                timeout=1.0,
            )
            motor.previous_raw_position = state.position
            enabled_motors.append(motor)

        for motor in motors:
            checked_state(motor, args.overspeed_limit)

        operator_velocity_commands = [0.0, 0.0]
        saved_positions: tuple[float, float] | None = None
        returning = False
        face_tracking = False
        hand_tracking = False
        face_tracker_started = False
        return_stable_since: float | None = None
        recorded_motion: list[MotionSample] = []
        recording = False
        record_started_at = 0.0
        last_record_at = 0.0
        replaying = False
        replay_phase = ""
        replay_elapsed = 0.0
        replay_last_update = 0.0
        replay_index = 0
        replay_stable_since: float | None = None
        previous_buttons = initial_buttons
        last_print = time.monotonic()
        next_send = time.monotonic()

        print()
        print("左摇杆：横轴控制电机1，纵轴控制电机2，偏转量控制速度")
        print("X 记录两电机位置，Y 自动返回记录位置；拨动摇杆可取消回位")
        print("十字键 ↓ 开关人脸跟随；人脸丢失时自动减速停止")
        print("十字键 ↑ 开关手部跟随；手部丢失时自动减速停止")
        print("十字键 ← 开始/结束动作录制，十字键 → 复现刚录制的动作")
        print("按住 A 立即制动；按 B、Back、Esc 或 Ctrl+C 退出并失能")
        print(
            f"满摇杆速度：横轴={args.max_speed * args.x_speed_scale:.2f}，"
            f"纵轴={args.max_speed:.2f} rad/s；"
            f"响应={args.ramp_time:.3f} s，死区={args.deadzone:.2f}，"
            f"各自相对软限位=±{args.position_limit:.2f} rad"
        )

        while True:
            states = [
                checked_state(motor, args.overspeed_limit)
                for motor in motors
            ]
            for motor, state in zip(motors, states):
                motor_delta = unwrap_delta(
                    state.position,
                    motor.previous_raw_position,
                )
                motor.previous_raw_position = state.position
                motor.relative_position += motor.direction * motor_delta

            stick_x, stick_y, buttons = controller.read()
            stick_x, stick_y = suppress_cross_axis(
                stick_x,
                stick_y,
                args.axis_lock_ratio,
            )
            pressed_buttons = buttons & ~previous_buttons
            previous_buttons = buttons

            exit_pressed = bool(
                buttons & (XINPUT_GAMEPAD_B | XINPUT_GAMEPAD_BACK)
            ) or key_is_down(VK_ESCAPE)
            if exit_pressed:
                print("\n收到退出命令，正在停止并失能两台电机……")
                break

            brake_pressed = bool(buttons & XINPUT_GAMEPAD_A)

            if pressed_buttons & XINPUT_GAMEPAD_DPAD_LEFT:
                if recording:
                    elapsed = time.monotonic() - record_started_at
                    recorded_motion.append(
                        MotionSample(
                            elapsed,
                            motors[0].relative_position,
                            motors[1].relative_position,
                        )
                    )
                    recording = False
                    print(
                        f"\n动作录制结束：{elapsed:.2f} 秒，"
                        f"{len(recorded_motion)} 个采样点"
                    )
                else:
                    returning = False
                    face_tracking = False
                    hand_tracking = False
                    replaying = False
                    return_stable_since = None
                    replay_stable_since = None
                    recorded_motion = [
                        MotionSample(
                            0.0,
                            motors[0].relative_position,
                            motors[1].relative_position,
                        )
                    ]
                    record_started_at = time.monotonic()
                    last_record_at = record_started_at
                    recording = True
                    print("\n动作录制开始，请使用左摇杆操作两台电机……")

            if pressed_buttons & XINPUT_GAMEPAD_DPAD_RIGHT:
                if recording:
                    print("\n正在录制，请先按十字键 ← 结束录制")
                elif len(recorded_motion) < 2:
                    print("\n没有可复现的动作，请先按十字键 ← 录制")
                else:
                    returning = False
                    face_tracking = False
                    hand_tracking = False
                    replaying = True
                    replay_phase = "return_start"
                    replay_stable_since = None
                    replay_index = 0
                    print(
                        f"\n准备复现 {recorded_motion[-1].elapsed:.2f} 秒动作，"
                        "先返回录制起点……"
                    )

            if pressed_buttons & XINPUT_GAMEPAD_X:
                saved_positions = (
                    motors[0].relative_position,
                    motors[1].relative_position,
                )
                returning = False
                replaying = False
                return_stable_since = None
                print(
                    f"\n已记录位置：M1={saved_positions[0]:+.4f} rad，"
                    f"M2={saved_positions[1]:+.4f} rad"
                )

            if pressed_buttons & XINPUT_GAMEPAD_Y:
                if saved_positions is None:
                    print("\n尚未记录位置，请先按 X")
                else:
                    face_tracking = False
                    hand_tracking = False
                    replaying = False
                    returning = True
                    return_stable_since = None
                    print(
                        f"\n开始返回记录位置：M1={saved_positions[0]:+.4f} rad，"
                        f"M2={saved_positions[1]:+.4f} rad"
                    )

            if pressed_buttons & XINPUT_GAMEPAD_DPAD_DOWN:
                returning = False
                replaying = False
                return_stable_since = None
                if face_tracking:
                    face_tracking = False
                    print("\n人脸跟随已关闭")
                else:
                    hand_tracking = False
                    face_tracker.set_mode("face")
                    if not face_tracker_started:
                        face_tracker.start()
                        face_tracker_started = True
                    face_tracking = True
                    print("\n人脸跟随已开启，正在等待摄像头检测人脸……")

            if pressed_buttons & XINPUT_GAMEPAD_DPAD_UP:
                returning = False
                replaying = False
                return_stable_since = None
                if hand_tracking:
                    hand_tracking = False
                    print("\n手部跟随已关闭")
                else:
                    face_tracking = False
                    face_tracker.set_mode("hand")
                    if not face_tracker_started:
                        face_tracker.start()
                        face_tracker_started = True
                    hand_tracking = True
                    print("\n手部跟随已开启，正在等待摄像头检测手掌……")

            # 自动回位期间只要主动拨动摇杆，就立即交还人工控制。
            manual_override = math.hypot(stick_x, stick_y) > 0.02
            if returning and (brake_pressed or manual_override):
                returning = False
                return_stable_since = None
                print("\n自动回位已取消")
            if face_tracking and (brake_pressed or manual_override):
                face_tracking = False
                print("\n人脸跟随已取消，切换到手动控制")
            if hand_tracking and (brake_pressed or manual_override):
                hand_tracking = False
                print("\n手部跟随已取消，切换到手动控制")
            if replaying and (brake_pressed or manual_override):
                replaying = False
                replay_stable_since = None
                print("\n动作复现已取消，切换到手动控制")

            if recording:
                now = time.monotonic()
                elapsed = now - record_started_at
                if now - last_record_at >= args.record_interval:
                    recorded_motion.append(
                        MotionSample(
                            elapsed,
                            motors[0].relative_position,
                            motors[1].relative_position,
                        )
                    )
                    last_record_at = now
                if elapsed >= args.record_max_duration:
                    recording = False
                    print(
                        f"\n已达到最长录制时间 {args.record_max_duration:.1f} 秒，"
                        "录制自动结束"
                    )
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

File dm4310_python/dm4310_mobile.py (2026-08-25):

"""通过局域网手机页面控制两台 DM-J4310。

手机只向本机 HTTP 服务发送归一化摇杆量；USB2FDCAN 的打开、
使能、限位、看门狗和失能全部在单独控制线程中执行。页面断联
0.25 秒先令速度回零，1.2 秒后自动失能两台电机。
"""

from __future__ import annotations

import argparse
import hmac
import json
import math
import queue
import secrets
import socket
import threading
import time
from dataclasses import dataclass
from http.server import BaseHTTPRequestHandler, ThreadingHTTPServer
from pathlib import Path
from typing import Any
from urllib.parse import parse_qs, urlsplit

from dmcan import DmCanContext, dmcan_device_type

from dm4310_dual_keyboard import MotorRuntime, checked_state
from dm4310_face_tracker import FaceTracker
from dm4310_keyboard import clamp, unwrap_delta
from dm4310_usb2fdcan import (
    CONTROL_PERIOD_S,
    Feedback,
    configure_classic_can_1m,
    pack_mit,
    parse_int,
    send,
    special,
    wait_until_enabled,
)


COMMAND_STALE_S = 0.25
AUTO_DISABLE_S = 1.20
MAX_REQUEST_BYTES = 4096


@dataclass(frozen=True)
class MotionSample:
    elapsed: float
    position_1: float
    position_2: float


def tracking_error_to_velocity(
    error: float,
    deadzone: float,
    gain: float,
    speed_limit: float,
) -> float:
    if abs(error) <= deadzone:
        return 0.0
    effective = math.copysign(
        (abs(error) - deadzone) / (1.0 - deadzone),
        error,
    )
    return clamp(gain * effective, speed_limit)


def interpolate_motion(
    samples: list[MotionSample],
    elapsed: float,
    start_index: int,
) -> tuple[tuple[float, float], tuple[float, float], int, bool]:
    if elapsed >= samples[-1].elapsed:
        final = samples[-1]
        return (
            (final.position_1, final.position_2),
            (0.0, 0.0),
            max(0, len(samples) - 2),
            True,
        )
    index = min(start_index, len(samples) - 2)
    while index + 1 < len(samples) and samples[index + 1].elapsed < elapsed:
        index += 1
    first, second = samples[index], samples[index + 1]
    duration = max(1e-6, second.elapsed - first.elapsed)
    alpha = max(0.0, min(1.0, (elapsed - first.elapsed) / duration))
    return (
        (
            first.position_1 + alpha * (second.position_1 - first.position_1),
            first.position_2 + alpha * (second.position_2 - first.position_2),
        ),
        (
            (second.position_1 - first.position_1) / duration,
            (second.position_2 - first.position_2) / duration,
        ),
        index,
        False,
    )


class DualMobileController:
    """两电机手机摇杆控制器。所有 SDK 操作只在 worker 线程中执行。"""

    def __init__(self, args: argparse.Namespace) -> None:
        self.args = args
        self._lock = threading.RLock()
        self._actions: queue.Queue[tuple[str, dict[str, Any]]] = queue.Queue()
        self._stop = threading.Event()
        self._context = None
        self._device = None
        self._channel_enabled = False
        self._motors: list[MotorRuntime] = []
        self._enabled_motors: list[MotorRuntime] = []

        self._mode = "disconnected"
        self._message = "等待连接 USB2FDCAN"
        self._enabled = False
        self._stick_x = 0.0
        self._stick_y = 0.0
        self._velocity_commands = [0.0, 0.0]
        self._last_command_at = 0.0
        self._last_control_at = time.monotonic()

        self._operation = "manual"
        self._vision_mode = "off"
        self._tracker_started = False
        self._tracker = FaceTracker(
            camera_index=args.camera_index,
            camera_name=args.camera_name,
            preview=False,
            stream=True,
            stream_fps=args.stream_fps,
            jpeg_quality=args.jpeg_quality,
        )
        self._saved_positions: tuple[float, float] | None = None
        self._return_stable_since: float | None = None
        self._recorded_motion: list[MotionSample] = []
        self._recording = False
        self._record_started_at = 0.0
        self._last_record_at = 0.0
        self._replay_elapsed = 0.0
        self._replay_last_update = 0.0
        self._replay_index = 0
        self._replay_stable_since: float | None = None

        self.max_speed = args.max_speed
        self.x_speed_scale = args.x_speed_scale
        self.ramp_time = args.ramp_time

        self._thread = threading.Thread(
            target=self._worker,
            name="dm4310-mobile-control",
            daemon=True,
        )
        self._thread.start()

    def enqueue(self, action: str, **payload: Any) -> None:
        self._actions.put((action, payload))

    def shutdown(self) -> None:
        self._stop.set()
        self._actions.put(("shutdown", {}))
        self._thread.join(timeout=4.0)

    def snapshot(self) -> dict[str, Any]:
        now = time.monotonic()
        with self._lock:
            motor_data: list[dict[str, Any]] = []
            for motor in self._motors:
                state = motor.feedback.snapshot()
                fresh = bool(state.received_at and now - state.received_at <= 0.5)
                motor_data.append(
                    {
                        "name": motor.name,
                        "slave_id": f"0x{motor.slave_id:02X}",
                        "master_id": f"0x{motor.master_id:02X}",
                        "position": motor.relative_position,
                        "velocity": motor.direction * state.velocity if fresh else None,
                        "torque": motor.direction * state.torque if fresh else None,
                        "temperature": state.mos_temperature if fresh else None,
                        "status": state.status if state.received_at else None,
                        "feedback_fresh": fresh,
                        "command_velocity": self._velocity_commands[len(motor_data)],
                    }
                )
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
